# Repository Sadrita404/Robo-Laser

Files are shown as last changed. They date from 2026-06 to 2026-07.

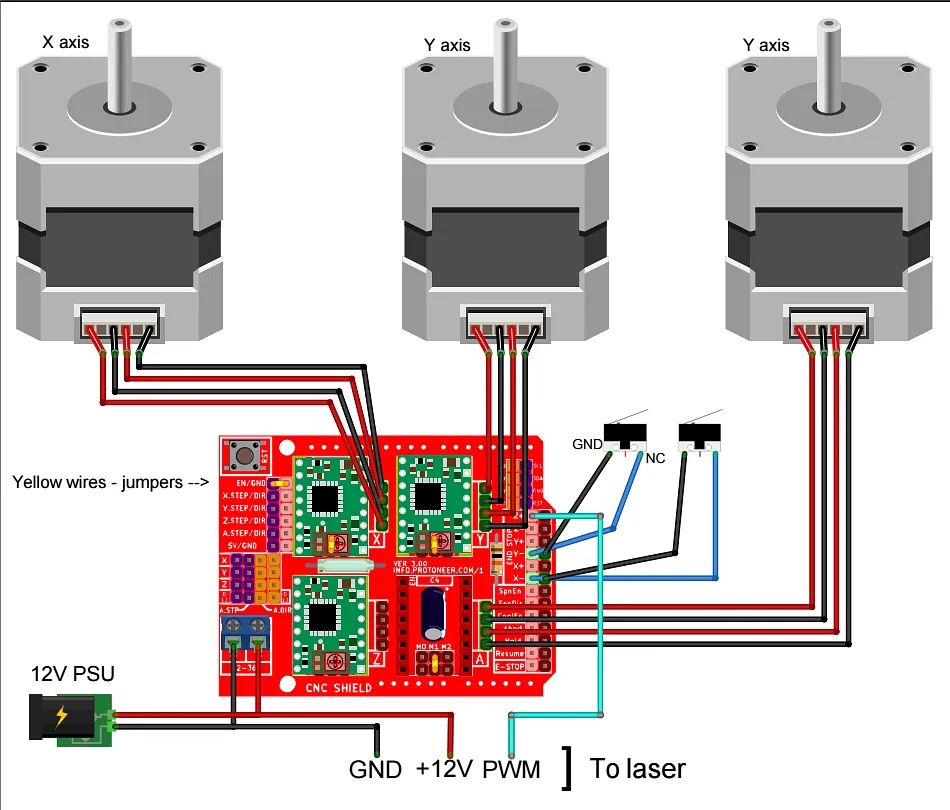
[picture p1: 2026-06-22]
IMAGE/Wiring Diagram Final .jpg

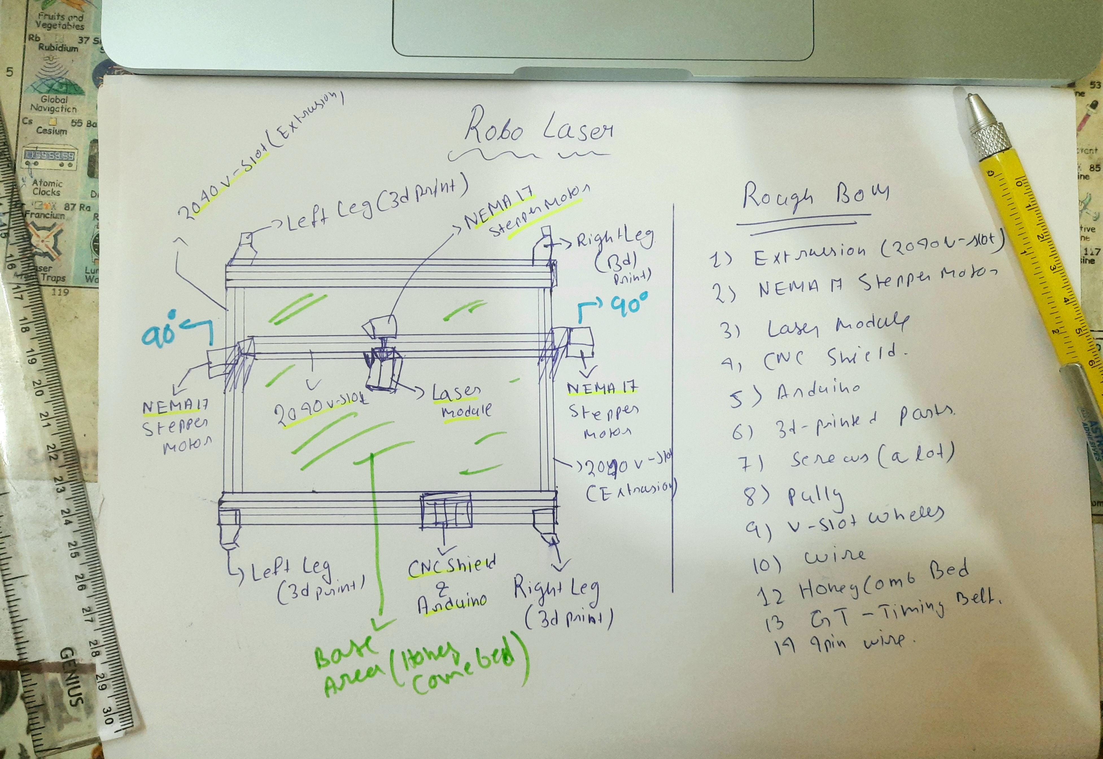
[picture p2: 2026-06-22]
IMAGE/sketch.jpg

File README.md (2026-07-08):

  <table border="0" cellpadding="0" cellspacing="0">
    <tr>
      <td align="center" style="background: #ffffff; border: 1px solid #d0d7de; border-radius: 12px; padding: 16px; box-shadow: 0 4px 12px rgba(0,0,0,0.05);">
        Rough Layout For The PCB
        <div style="margin-top: 12px; font-family: -apple-system, BlinkMacSystemFont, 'Segoe UI', Helvetica, Arial, sans-serif; font-size: 13px; color: #57606a; font-weight: 500;">
      </td>
    </tr>
  </table>
</div>

|Title | Robo Laser |
|:-- |:--|
|Author | Sadrita Neogi|

## Overview
It's an hobby grade laser engraver that I have made the model in fusion 360 and after that, I have specifically selected the components that fits the budget and it is easily modified and it can be later upgraded into something related to CNC. And this is an open source project.

### Why I chose this project?
I chose to build a CNC laser engraver because it combines both the hardware and the software and while making it I have learnt a lot about CAD design how to take dimension from data sheet and implemented in CAD also learned about how XY coordinate works in an CNC

### How to use this project
This can be used in various ways for me. I will use it to engrave in small MDF board for my projects, and I can also cut small things with it like if I want to make an keyboard, I can cut out the base plate for the keyboard with it with extreme accuracy and it will enhance the project quality. Also, it can be used in other way too.

---

<div align="center">
  <table border="0" cellpadding="0" cellspacing="0">
    <tr>
      <td align="center" style="background: #ffffff; border: 1px solid #d0d7de; border-radius: 12px; padding: 16px; box-shadow: 0 4px 12px rgba(0,0,0,0.05);">
        Rough Layout For The PCB
        <div style="margin-top: 12px; font-family: -apple-system, BlinkMacSystemFont, 'Segoe UI', Helvetica, Arial, sans-serif; font-size: 13px; color: #57606a; font-weight: 500;">
      </td>
    </tr>
  </table>
</div>

|  | CAD WORK |  |  
| :-: | :-: | :-: |
| Full Board Layout | Component Placement | Connection Map |
| Trace Routing Detail | Alternate Connection Map | Secondary Trace Detail |
| Component Placement 2 | Routing Detail 3 | Routing Detail 4 |
| Routing Detail 5 | Routing Detail 6 | Final Routing Detail |

---
## Wiring Diagram 

<p align="center">
  
  
</p>

## Setup -  [setup.md](https://github.com/Sadrita404/Robo-Laser/blob/main/setup.md)

Once the machine is assembled and wired, firmware needs to be installed so that it can move.

### Flashing GRBL onto the Arduino
GRBL is the firmware which is going to run on the Arduino and interpret the G-code commands. The installation is fairly simple.

1. **Download the Arduino IDE** from their site, a program which allows to flash the Arduino with firmware.
2. **Download GRBL source code** `.zip` file from the GitHub repository: https://github.com/gnea/grbl/releases and unzip the grbl file. 
   > **Note:** Before we proceed, we need to modify the `config.h` file inside grbl to account for the lack of the Z axis.
3. **Open Arduino IDE and import the grbl file** via: `Sketch` -> `Include Library` -> `Add .ZIP Library...` *(it says .ZIP but the uncompressed file should be chosen)*.
4. **Navigate to the grblUpload sketch** via: `File` -> `Examples` -> `grbl` -> `grblUpload`.
6. **Flash the sketch** through `Sketch` -> `Upload`.

---

### Connecting the Arduino to LaserGRBL

1. **Download LaserGRBL** from their website: https://lasergrbl.com and install it.
2. **Choose the correct port** and select **"115200" baud rate**, then click **Connect**. 

If the console shows `Grbl 1.1h`, the chip is connected.

##  Now for sending the G- Code to the Arduino I will use universal Gcode Sender 

**https://github.com/winder/Universal-G-Code-Sender**

- official website - https://winder.github.io/ugs_website/

- It is an open source software, which is used to control CNC machines to send G code to them and to use it

---
<div align="center">
  <h2> Final Look After Render </h2>
</div>

<p align="center">
  
</p>

<p align="center">
  
</p>

<p align="center">
  
</p>

<p align="center">
  
</p>

<div align="center">
  <h2> Bill of Materials</h2>
</div>

| Component Name | Purpose | Qty | Total Price | Source Link | Distributor |
| :--- | :--- | :---: | :---: | :---: | :---: |
| **4W Laser Engraver with adjustable Focus** | Laser cutting/engraving tool | 1 | $90 | [Amazon](https://www.amazon.in/LASER-TREE-20W-Adjustable-450nm/dp/B09BKJDPDJ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) | Amazon |
| **M5 Hex Nut** | General assembly fastening | 20 | $0.17 | [OnlyScrews](https://onlyscrews.in/products/m5-hex-nut-mild-steel-grey-dia-5mm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) | onlyscrews |
| **M5 x 10mm** | Extrusion/bracket fastening | 20 | $0.51 | [OnlyScrews](https://onlyscrews.in/products/m5-x-10mm-hex-allen-button-head-high-tensile10-9-black-oxide-screw-dia-5mm-length-10mm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) | onlyscrews |
| **M3 X 8mm Hex** | Motor/shield component mounting | 20 | $0.55 | [OnlyScrews](https://onlyscrews.in/products/m3-x-8mm-hex-allen-button-head-hight-tensile10-9-black-oxide-screw-dia-3mm-length-8mm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) | onlyscrews |
| **M5 X 35mm Hex** | Gantry/structural fastening | 20 | $0.76 | [OnlyScrews](https://onlyscrews.in/products/m5-x-35mm-hex-allen-button-head-high-tensile10-9-black-oxide-screw-dia-5mm-length-35mm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) | onlyscrews |
| **A4988 Driver Stepper Motor Driver** | Stepper motor control interface | 4 | $2.54 | [FlyRobo](https://www.flyrobo.in/a4988-driver-stepper-motor-driver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) | flyrobo |
| **Allen Key** | 	To fix the Rails | 1 | $2.11 | [onlyscrews](https://onlyscrews.in/products/allen-key-mm-set-m1-5-to-m10-chrome-vanadium-steel?variant=49975496671545) | amazon |
| **5 mm Tap set** | 		To make holes in the Extrusion Rod | 1 | $5.60 | [amazon](https://www.amazon.in/gp/product/B0D1R57NP7/ref=ox_sc_act_title_1?smid=A1ONML66JO9EQE&psc=1) | onlyscrews |
| **T-Slot inside corner connector for 2020** | Rigid frame joint support | 1 | $2.82 | [Robu](https://robu.in/product/easymech-2020-series-corner-slot-connector/?) | Robu |
| **Mech Endstop Switch** | Axis limit/homing switches | 8 | $3.99 | [Robu](https://robu.in/product/cnc-3d-printer-mech-endstop-switch/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) | robu |
| **T-Slot inside corner connector for 2020** | Rigid frame joint support | 1 | $2.82 | [Robu](https://robu.in/product/easymech-2020-series-corner-slot-connector/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) | robu |
| **NEMA 17 Stepper Motor, Bipolar, 1.5A** | Axis motion actuation | 3 | $22.79 | [Robu](https://robu.in/product/nema17-pr42hs40-1204af-02-4-2kg-cm-stepper-motor-d-type-shaft/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) | robu |
| **arduino uno r3 board** | Stepper motor control interface | 1 | $2.28 | [Robu](https://robu.in/product/arduino-uno-r3-ch340g-atmega328p-devlopment-board/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) | robu |
| **CNC Shield V3** | Stepper motor control interface | 1 | $1.48 | [FlyRobo](https://www.flyrobo.in/cnc-shield-v3-for-engraving-machine-3d-printer-a4988-drv8825-driver-expansion-board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) | flyrobo |
| **V Slot gantry wheel(625zz)** | Gantry linear movement | 14 | $8.46 | [FlyRobo](https://www.flyrobo.in/openbuilds-plastic-wheel-idler-pulley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) | flyrobo |
| **GT2 Timing Belt, 5M, 6mm width** | Linear motion drive | 1 | $4.66 | [Robu](https://robu.in/product/5-meter-x-gt2-open-timing-belt-6mm-width/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) | robu |
| **2040 Aluminum Extrusion, 1000mm V Slot** | Main structural frame | 2 | $19.6 | [Robu](https://robu.in/product/easymech-20x40-6t-slot-aluminium-extrusion-profile-1000-mm/) | robu |
| **2040 Aluminum Extrusion, 500mm V Slot** | Main structural frame | 3 | $17 | [Robu](https://robu.in/product/easymech-20x40-6t-slot-aluminium-extrusion-profile-500mm/) | robu |
| **20 Tooth 5mm Bore GT2 Timing Pulley** | Belt drive transmission | 6 | $2.09 | [FlyRobo](https://www.flyrobo.in/20-teeth-5mm-bore-gt2-black-timing-pulley-for-6mm-belt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) | flyrobo |
| **M5 X 100mm Hex** | Structural fastening | 1 | $0.34 | [link](https://3fparts.com/shop/m5-100mm-hex-bolt-din-933-stainless-steel-304-a2-70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) | Self - Sourced |
| **M4 X 100mm Hex** | Structural fastening | 2 | $0.89 | [OnlyScrews](https://onlyscrews.in/products/m4-x-100mm-hex-allen-socket-head-ss-304-screw-dia-4mm-length-100mm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) | onlyscrews |
| **M5 Profile Nuts** | Frame assembly hardware | 20 | $1.90 | [OnlyScrews](https://onlyscrews.in/products/m4-profile-nuts-mild-steel-with-nickel-plating-for-3030-series-t-nut-hammer-nut-1) | onlyscrews |
| **M4 Profile Nuts** | Frame assembly hardware | 20 | $1.84 | [OnlyScrews](https://onlyscrews.in/products/m4-profile-nuts-mild-steel-with-nickel-plating-for-2020-series-t-nut-hammer-nut) | onlyscrews |
| **M3 Profile Nuts** | Frame assembly hardware | 20 | $1.80 | [OnlyScrews](https://onlyscrews.in/products/m3-profile-nuts-mild-steel-with-nickel-plating-for-2020-series-t-nut-hammer-nut) | onlyscrews |
| **Cable with Connector for NEMA17 Motor** | Motor connection | 4 | $1.90 | [Robu](https://robu.in/product/pure-copper-1000-mm-cable-with-connector-for-nema17-stepper-motor/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) | robu |
| **Honeycomb Working Bed** | For the laser engraving area | 1 | $35 | [Robu](https://robu.in/product/two-trees-honeycomb-working-400x400-panel-set/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) | robu |
| **Power Supply** | to power up the circuit | 1 | $22 | [Robu](https://robu.in/product/mean-well-lrs-200-24-24v-8-8a-211-2w-smps/) | robu |

<div align="center">
  <table border="0" cellpadding="0" cellspacing="0" style="border-collapse: collapse; max-width: 600px;">
    <tr>
      <td style="background: #ffffff; border: 1px solid #d0d7de; border-radius: 12px; padding: 20px; box-shadow: 0 4px 12px rgba(0,0,0,0.05); font-family: -apple-system, BlinkMacSystemFont, 'Segoe UI', Helvetica, Arial, sans-serif;">
        <div style="font-size: 16px; font-weight: 600; color: #24292f; margin-bottom: 12px; border-bottom: 1px solid #d0d7de; padding-bottom: 8px;">
          Final Bill
        </div>
        <table width="100%" border="0" style="border-collapse: collapse; font-size: 14px; color: #57606a;">
          <tr>
            <td style="padding: 4px 0;">Component Subtotal:</td>
            <td align="right" style="font-weight: 500; color: #24292f;">$242</td>
          </tr>
          <tr>
            <td style="padding: 4px 0;"> Shipping:</td>
            <td align="right" style="font-weight: 500; color: #24292f;">$6.3</td>
          </tr>
          <tr>
            <td style="padding: 4px 0; padding-bottom: 8px;"> Tax:</td>
            <td align="right" style="font-weight: 500; color: #24292f;">$1.1</td>
          </tr>
          <tr style="border-top: 1px dashed #d0d7de;">
            <td style="padding: 12px 0 0 0; font-weight: 600; color: #24292f; font-size: 15px;">Net Total Cost:</td>
            <td align="right" style="padding: 12px 0 0 0; font-weight: bold; color: #2da44e; font-size: 18px;">$249.4</td>
          </tr>
          <tr>
            <td style="padding: 2px 0 0 0; font-size: 11px; color: #8c959f;">Projected Budget Allocation:</td>
            <td align="right" style="padding: 2px 0 0 0; font-weight: 500; font-size: 12px; color: #8c959f;">$250</td>
          </tr>
        </table>
      </td>
    </tr>
  </table>
</div>

I have provided the links to the parts that I will self - sourced , So that if a reader wanted to recreate this project they would be able to find all the parts..

**Project Under Hack Club**

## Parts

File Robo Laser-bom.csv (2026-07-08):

Name | Purpose | Quantity | Total Cost (USD) | Link | Distributor
Allen Key | To fix the Rails | 1 | 2.11 | https://onlyscrews.in/products/allen-key-mm-set-m1-5-to-m10-chrome-vanadium-steel?variant=49975496671545 | onlyscrews
5 mm Tap set | To make holes in the Extrusion Rod | 1 | 5.60 | https://www.amazon.in/gp/product/B0D1R57NP7/ref=ox_sc_act_title_1?smid=A1ONML66JO9EQE&psc=1 | amazon
4W Laser Engraver with adjustable Focus | Laser cutting/engraving tool | 1 | 90 | https://www.amazon.in/LASER-TREE-20W-Adjustable-450nm/dp/B09BKJDPDJ?mcid=b94e30e433d33609930a239af455c954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 | Amazon
M5 Hex Nut | General assembly fastening | 20 | 0.17 | https://onlyscrews.in/products/m5-hex-nut-mild-steel-grey-dia-5mm?currency=INR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 | onlyscrews
M5 x 10mm | Extrusion/bracket fastening | 20 | 0.51 | https://onlyscrews.in/products/m5-x-10mm-hex-allen-button-head-high-tensile10-9-black-oxide-screw-dia-5mm-length-10mm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 | onlyscrews
M3 X 8mm Hex | Motor/shield component mounting | 20 | 0.55 | https://onlyscrews.in/products/m3-x-8mm-hex-allen-button-head-hight-tensile10-9-black-oxide-screw-dia-3mm-length-8mm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 | onlyscrews
M5 X 35mm Hex | Gantry/structural fastening | 20 | 0.76 | https://onlyscrews.in/products/m5-x-35mm-hex-allen-button-head-high-tensile10-9-black-oxide-screw-dia-5mm-length-35mm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 | onlyscrews
A4988 Driver Stepper Motor Driver | Stepper motor control interface | 4 | 2.54 | https://www.flyrobo.in/a4988-driver-stepper-motor-driver?tracking=ads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 | flyrobo
Mech Endstop Switch | Axis limit/homing switches | 8 | 3.99 | https://robu.in/product/cnc-3d-printer-mech-endstop-switch/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 | robu
T-Slot inside corner connector for 2020 | Rigid frame joint support | 1 | 2.82 | https://robu.in/product/easymech-2020-series-corner-slot-connector/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 | robu
NEMA 17 Stepper Motor, Bipolar, 1.5A | Axis motion actuation | 3 | 22.79 | https://robu.in/product/nema17-pr42hs40-1204af-02-4-2kg-cm-stepper-motor-d-type-shaft/?gad_source=1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 | robu
arduino uno r3 board | Stepper motor control interface | 1 | 2.28 | https://robu.in/product/arduino-uno-r3-ch340g-atmega328p-devlopment-board/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 | robu
CNC Shield V3 | Stepper motor control interface | 1 | 1.48 | https://www.flyrobo.in/cnc-shield-v3-for-engraving-machine-3d-printer-a4988-drv8825-driver-expansion-board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 | flyrobo
V Slot gantry wheel(625zz) | Gantry linear movement | 14 | 8.46 | https://www.flyrobo.in/openbuilds-plastic-wheel-idler-pulley?tracking=ads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 | flyrobo
GT2 Timing Belt, 5M, 6mm width | Linear motion drive | 1 | 4.66 | https://robu.in/product/5-meter-x-gt2-open-timing-belt-6mm-width/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 | robu
2040 Aluminum Extrusion, 1000mm V Slot | Main structural frame | 2 | 19.6 | https://robu.in/product/easymech-20x40-6t-slot-aluminium-extrusion-profile-1000-mm/ | robu
2040 Aluminum Extrusion, 500mm V Slot | Main structural frame | 3 | 17 | https://robu.in/product/easymech-20x40-6t-slot-aluminium-extrusion-profile-500mm/ | robu
20 Tooth 5mm Bore GT2 Timing Pulley | Belt drive transmission | 6 | 2.09 | https://www.flyrobo.in/20-teeth-5mm-bore-gt2-black-timing-pulley-for-6mm-belt?tracking=ads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 | flyrobo
M5 X 100mm Hex | Structural fastening | 1 | 0.34 | https://3fparts.com/shop/m5-100mm-hex-bolt-din-933-stainless-steel-304-a2-70 | Self - Sourced
M4 X 100mm Hex | Structural fastening | 2 | 0.89 | https://onlyscrews.in/products/m4-x-100mm-hex-allen-socket-head-ss-304-screw-dia-4mm-length-100mm?currency=INR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 | onlyscrews
M5 Profile Nuts | Frame assembly hardware | 20 | 1.90 | https://onlyscrews.in/products/m4-profile-nuts-mild-steel-with-nickel-plating-for-3030-series-t-nut-hammer-nut-1 | onlyscrews
M4 Profile Nuts | Frame assembly hardware | 20 | 1.84 | https://onlyscrews.in/products/m4-profile-nuts-mild-steel-with-nickel-plating-for-2020-series-t-nut-hammer-nut | onlyscrews
M3 Profile Nuts | Frame assembly hardware | 20 | 1.80 | https://onlyscrews.in/products/m3-profile-nuts-mild-steel-with-nickel-plating-for-2020-series-t-nut-hammer-nut | onlyscrews
Cable with Connector for NEMA17 Stepper Motor | Motor connection | 4 | 1.90 | https://robu.in/product/pure-copper-1000-mm-cable-with-connector-for-nema17-stepper-motor/?gad_source=1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 | robu
Honeycomb Working Bed | For the laser engraving area | 1 | 35 | https://robu.in/product/two-trees-honeycomb-working-400x400-panel-set/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 | Robu
Power Supply | to power up the main circuit | 1 | 22 | https://robu.in/product/mean-well-lrs-200-24-24v-8-8a-211-2w-smps/ | Robu

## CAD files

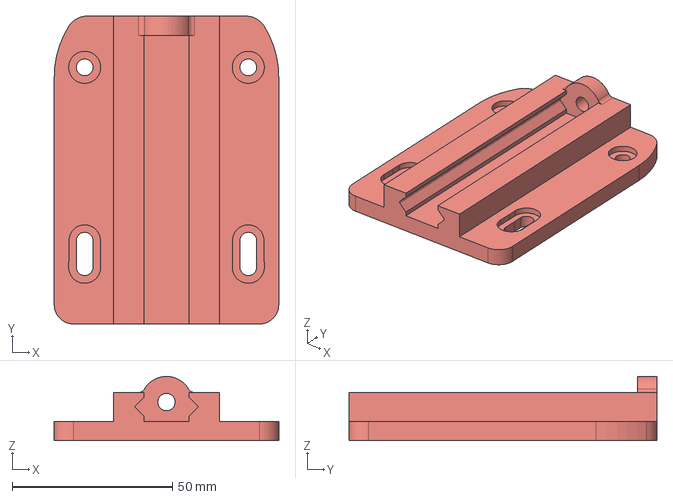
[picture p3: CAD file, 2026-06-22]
CAD/02 Laser Holder Base [x1].step
70.0 x 96.0 x 20.0 mm

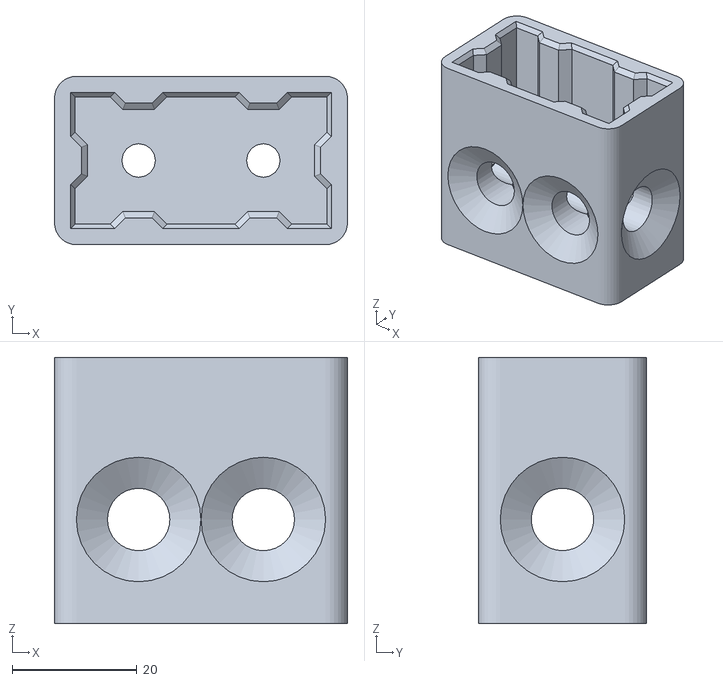
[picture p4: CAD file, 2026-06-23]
STL/[x2]M5 V-Slot 2040.stl
47.0 x 27.0 x 42.7

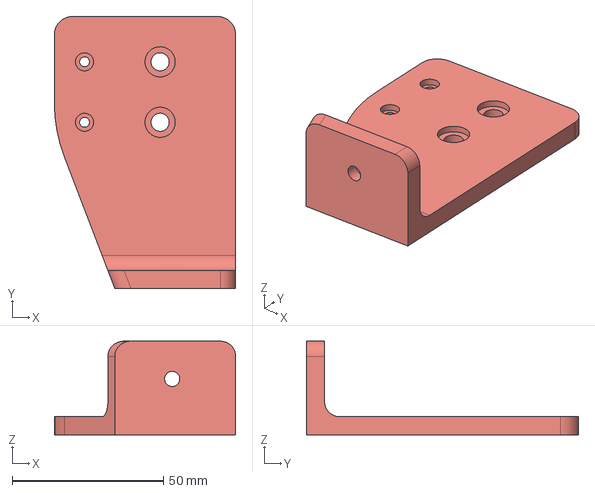
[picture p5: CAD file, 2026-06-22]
CAD/Right Leg.step
60.0 x 90.0 x 31.0 mm

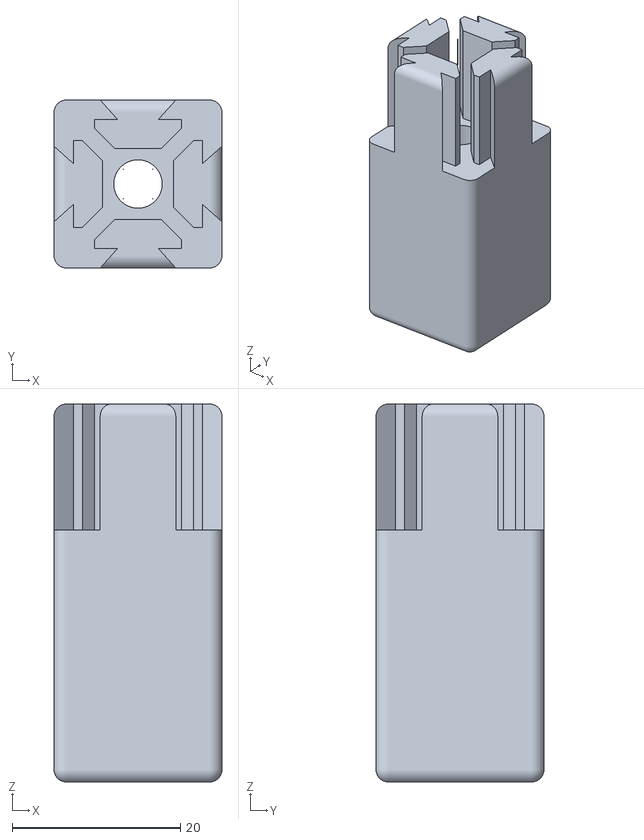
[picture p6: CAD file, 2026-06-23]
STL/[x2]V-Slot apping.stl
20.0 x 20.0 x 45.0

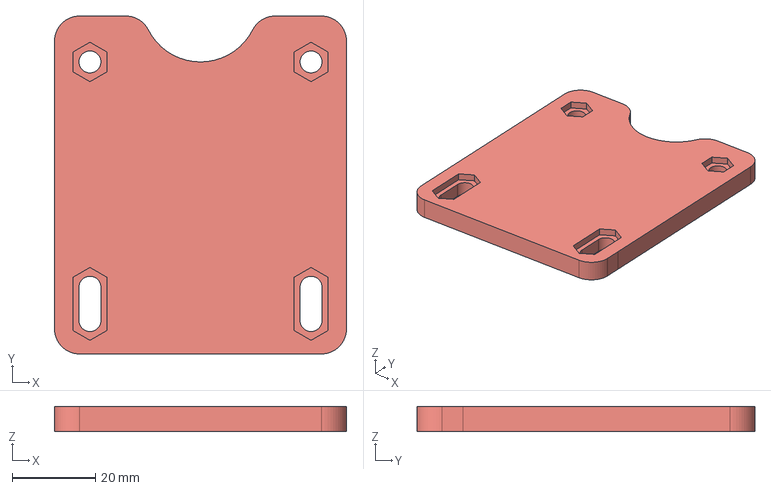
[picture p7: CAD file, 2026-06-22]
CAD/Y-Drive Side Panel.step
70.0 x 81.0 x 6.00 mm

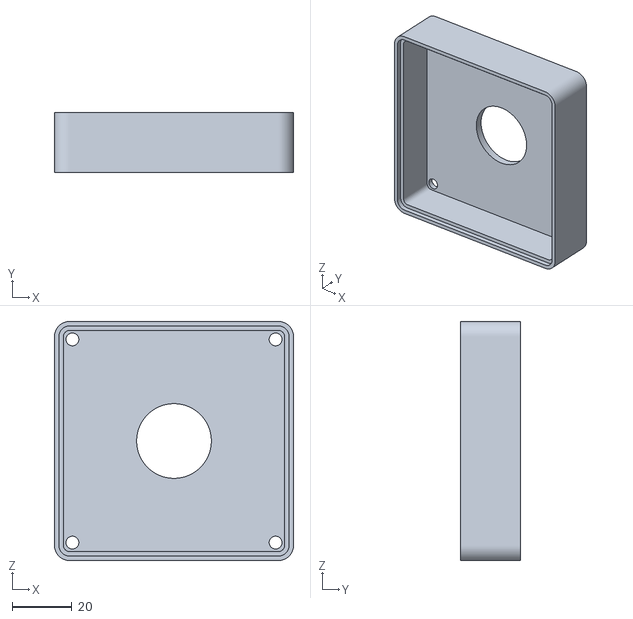
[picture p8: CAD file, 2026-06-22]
STL/[x1]E-Stop box top.stl
80.0 x 20.0 x 80.0

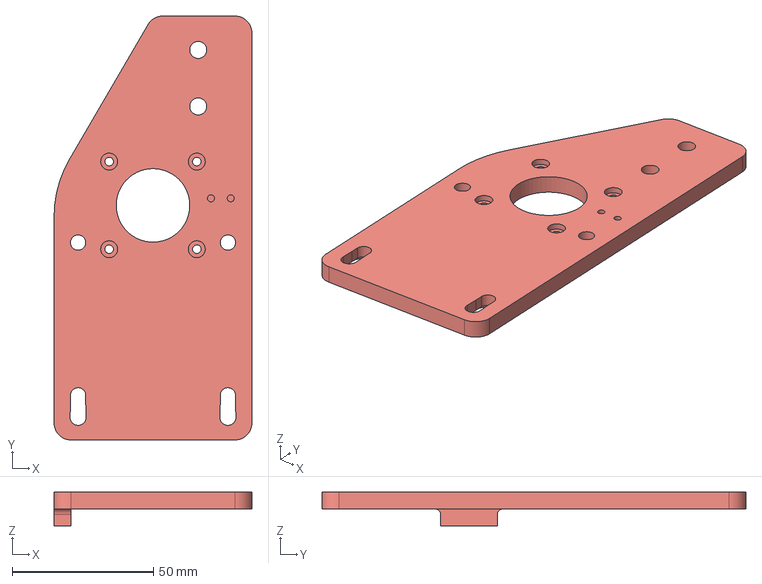
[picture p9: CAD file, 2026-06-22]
CAD/06 Y-Drive Panel L.step
70.0 x 150.0 x 12.0 mm

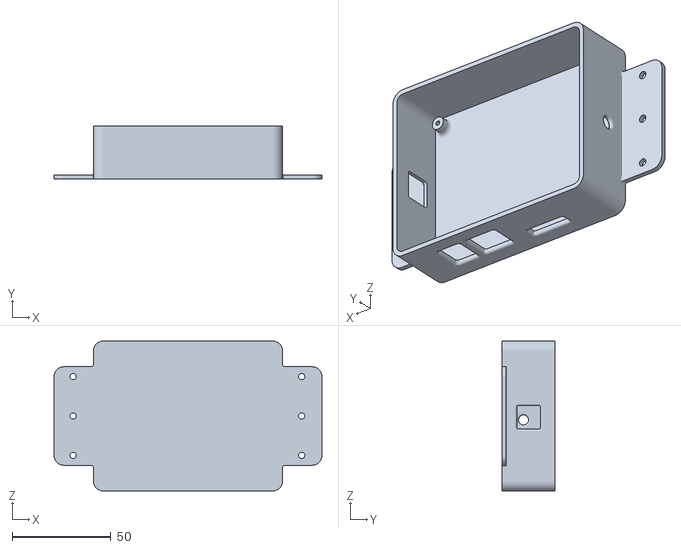
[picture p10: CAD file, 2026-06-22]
STL/[x1]Enclosure Body.stl
136.0 x 27.0 x 76.0

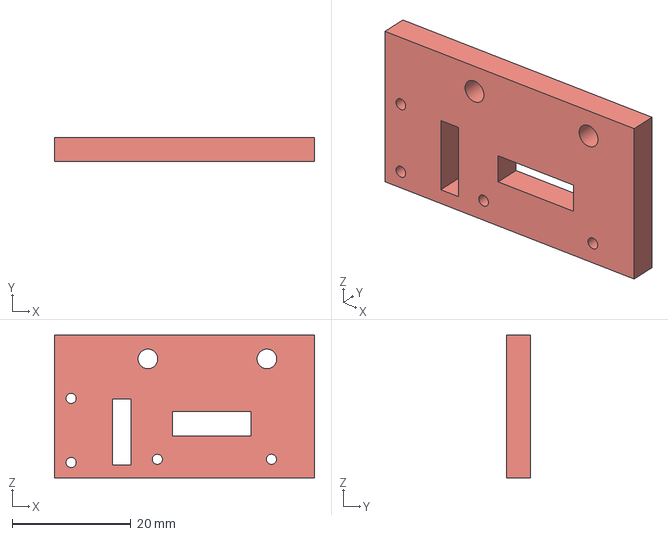
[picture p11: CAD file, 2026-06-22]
CAD/Limit switch mount.step
43.7 x 4.00 x 24.0 mm

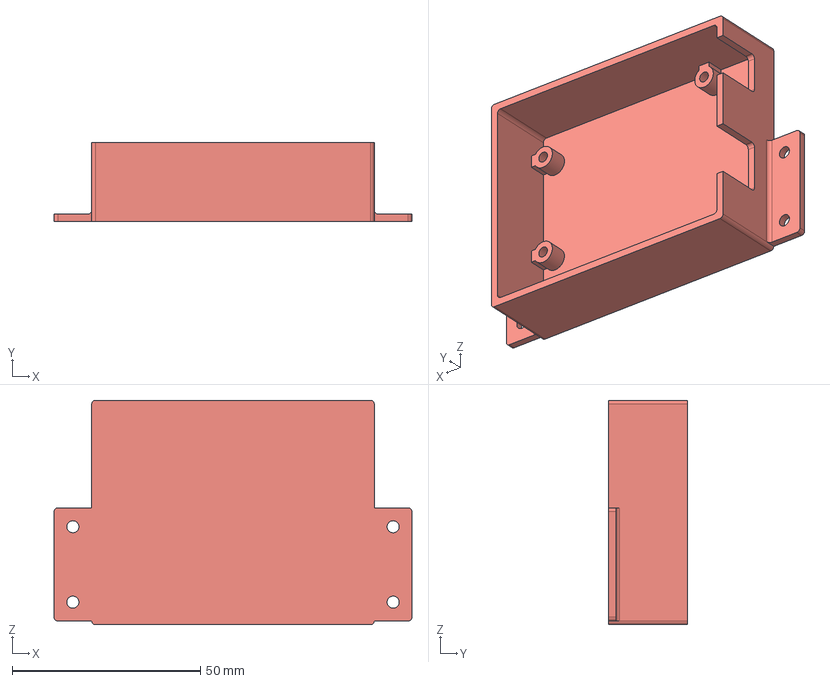
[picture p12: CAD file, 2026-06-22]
CAD/Uno and CNC Shield holder.step
95.0 x 21.0 x 59.6 mm

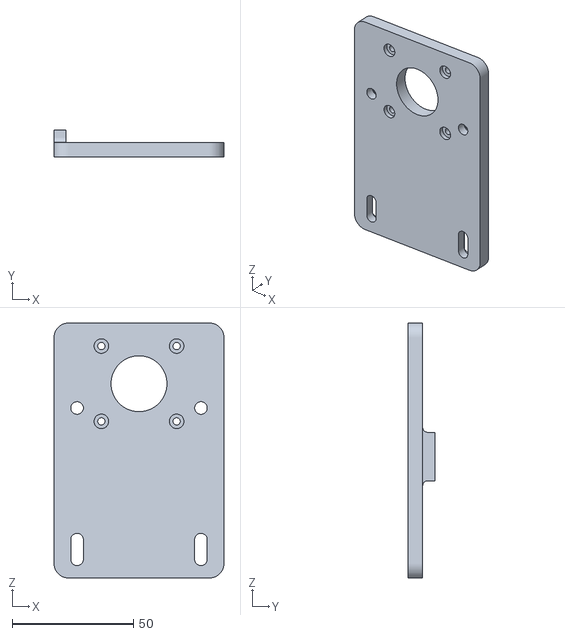
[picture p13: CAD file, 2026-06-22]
STL/[x4]X-Axis Stepper Mount.stl
70.0 x 11.0 x 105.0

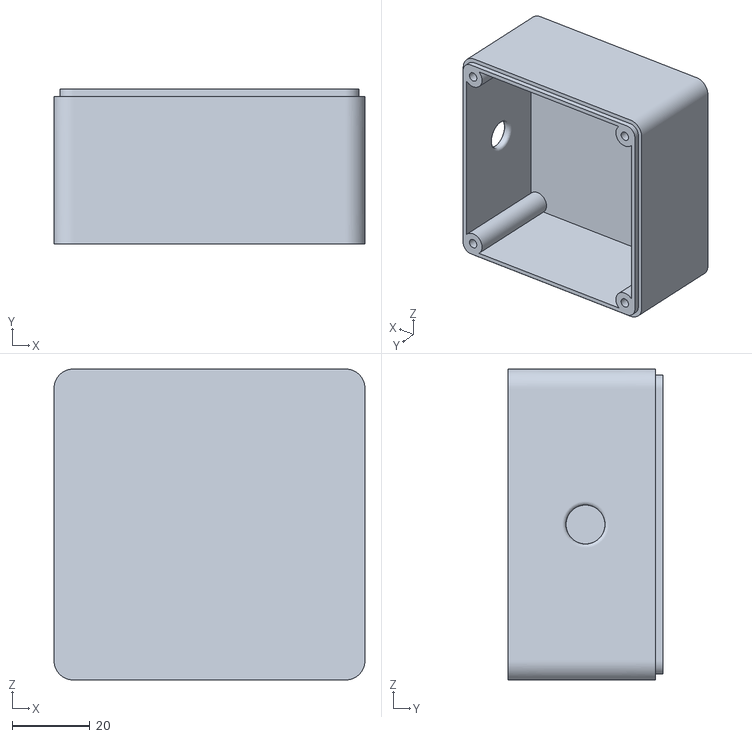
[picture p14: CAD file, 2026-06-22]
STL/[x1]E-Stop box bottom.stl
80.0 x 40.0 x 80.0

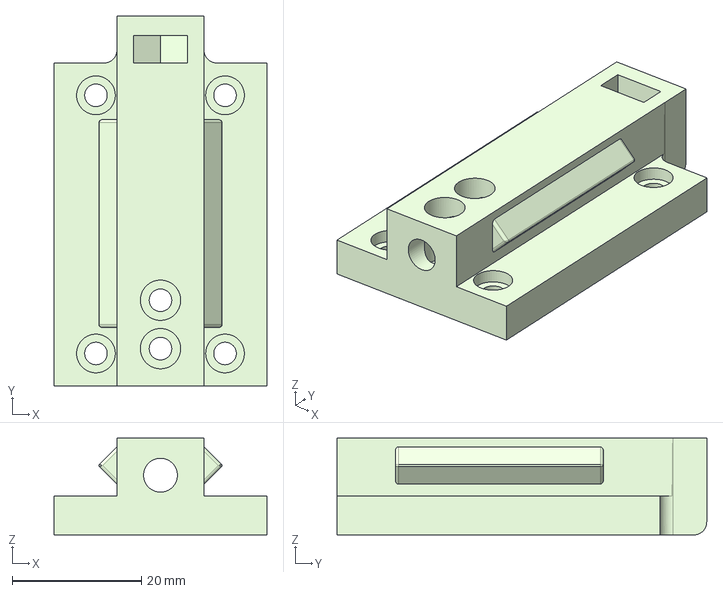
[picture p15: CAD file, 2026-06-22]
CAD/01 Laser Mount [x2].step
33.0 x 57.3 x 15.0 mm

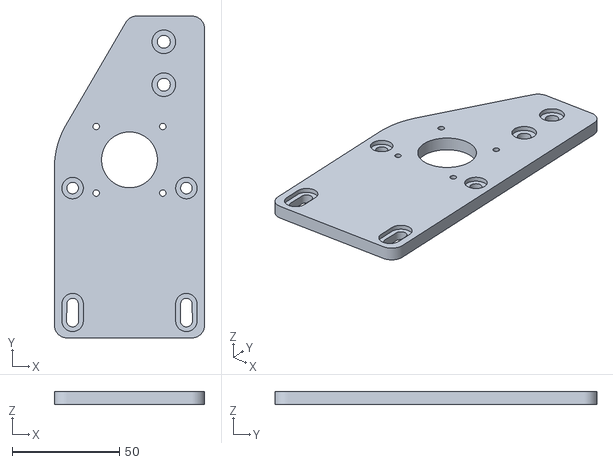
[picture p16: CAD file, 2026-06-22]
STL/[x2]Y-Drive Panel R.stl
70.0 x 150.0 x 6.00

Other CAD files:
STL/[x4]Y-Drive Side Panel.stl
CAD/03 X-Axis Stepper Mount.step
STL/[x1]Uno and CNC Shield holder.stl
CAD/Left Leg.step
CAD/01 Laser Mount [x2].f3d
CAD/02 Laser Holder Base [x1].f3d
CAD/03 X-Axis Stepper Mount.f3d
CAD/04 Laser Focus Knob.f3d
CAD/04 Laser Focus Knob.step
CAD/05 V-Wheel Bushing.f3d
CAD/05 V-Wheel Bushing.step
CAD/06 Y-Drive Panel L.f3d
CAD/Left Leg.f3d
CAD/Limit switch mount.f3d
CAD/Right Leg.f3d
CAD/Uno and CNC Shield holder.f3d
CAD/Y-Drive Side Panel.f3d
STL/[x1]Display Holder Back.stl
STL/[x1]Display Holder.stl
STL/[x1]Enclosrue Lid.stl
STL/[x1]Laser Focus Knob.stl
STL/[x1]Laser Mount 16mm x 40mm.stl
STL/[x1]Laser Mount 20mm x 40mm.stl
STL/[x2]Laser holder base.stl
STL/[x2]Left Leg.stl
STL/[x2]Right Leg.stl
STL/[x2]Y-Drive Panel L.stl
STL/[x40]V-Wheel Bushing v1.stl
STL/[x4]Limit switch mount.stl

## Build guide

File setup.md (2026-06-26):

## This are some of the thing that we need to keep in mind during building this 

For more details follow this - https://lasergrbl.com/usage/arduino-connection/

### I have use an unique way to setup software with extreme precision I went online searching for documentation for product that are available in online shops then I found this one which is listed on Amazon and they have good documentation and for building this kind of project, I think setting up the software with guided would be better
 PDF DOC - https://m.media-amazon.com/images/I/C1yvvKE-JJL.pdf

#### Flashing GRBL onto the Arduino

1. Download the Arduino IDE from their site, a program which allows to flash the Arduino with firmware.
2. Download GRBL source code.zip file from the GitHub repository: https://github.com/gnea/grbl/releases and unzip the grbl file. Before we proceed a we need to modify the config.h file inside grbl to account for the lack of the Z axis.
3. 
Screenshot 2026-06-23 at 2.59.49 AM

## Now , 
Screenshot 2026-06-23 at 3.00.07 AM

1. Open Arduino IDE and import the grbl file via: Sketch->Include Library->add .zip library.
2. Navigate to the grblUpload sketch via: File -> Examples -> grbl -> grblUpload
3. Connect the Arduino to the laptop via USB (make sure the correct board and port is selected).
4. Flash the sketch through Sketch->Upload

After that we need to connect  the Arduino to LaserGRBL(through which I will control the laser) is simple. First, download LaserGRBL from their website: [https://lasergrbl.com](https://lasergrbl.com) and install it. Then again connect the Arduino to the laptop  via USB, choose the correct port and select "115200" baud rate, then click connect. If the console shows "Grbl 1.1h, the chip is connected.

### Now to configure it correctly go through the doc below : - 
[DOC PDF ](https://lasergrbl.com/wp-content/uploads/2020/05/Grbl-Configuration-ENG.pdf)

 #### Key changes Main

### 1) Configuring Stepper Drivers

**Microstepping Jumpers**

Under each stepper driver socket on the CNC Shield V3 are three jumper pairs (MS1, MS2, MS3). These set the microstepping mode:

| MS1 | MS2 | MS3 | Microstepping (A4988) |
| :---: | :---: | :---: | :---: |
| **OFF** | **OFF** | **OFF** | Full step |
| **ON** | **OFF** | **OFF** | 1/2 step |
| **OFF** | **ON** | **OFF** | 1/4 step |
| **ON** | **ON** | **OFF** | 1/8 step |
| **ON** | **ON** | **ON** | 1/16 step |

Most 3018 CNC routers use 1/8 or 1/16 microstepping. Higher microstepping = smoother motion but lower maximum speed (due to GRBL’s step frequency limit). 1/8 stepping is a good balance.

### Setting Current Limit (VREF)
The most critical stepper driver adjustment is current limit. Over-current burns motors and drivers; under-current causes missed steps. Use a multimeter in DC voltage mode:

Measure VREF between the driver’s trimpot (center of the small adjustable potentiometer) and GND.

1)**For A4988: Imax = VREF / 0.625 (with 0.1Ω sense resistors). Set VREF = (rated motor current × 0.625).**

2)**For DRV8825: Imax = VREF / 0.5. Set VREF = (rated motor current / 2).**

3)**Start at 70–80% of motor rated current. For a 1.7A NEMA17: VREF ≈ 0.85V on A4988.**

### 2) GRBL Settings ($ Parameters)

**Type $$ in your GRBL sender to see all current settings. Here are the most important ones:**

| Parameter | Description | Typical Value (3018) |
| :---: | :--- | :--- |
| **$0** | Step pulse time (µs) | 10 |
| **$1** | Step idle delay (ms) | 25 (255 = always on) |
| **$2** | Step port invert (bitmask) | 0 |
| **$3** | Direction port invert (bitmask) | 0 (adjust if axes move wrong direction) |
| **$4** | Step enable invert | 0 |
| **$5** | Limit pin invert (NC vs NO switches) | 0 (NC=1) |
| **$10** | Status report mask | 1 |
| **$20** | Soft limits enable | 0 (1 if homing enabled) |
| **$21** | Hard limits enable | 0 (1 with limit switches) |
| **$22** | Homing cycle enable | 0 (1 with limit switches) |
| **$100** | X steps/mm | 800 (varies by machine) |
| **$101** | Y steps/mm | 800 |
| **$102** | Z steps/mm | 800 |
| **$110** | X max rate (mm/min) | 800 |
| **$111** | Y max rate (mm/min) | 800 |
| **$112** | Z max rate (mm/min) | 400 (Z is slower) |
| **$120** | X acceleration (mm/s²) | 40 |
| **$130** | X max travel (mm) | 300 (your machine’s X range) |

Change any setting by typing the parameter and value, e.g.: $100=800 followed by Enter. Changes are saved to Arduino EEPROM immediately.

### 3) Calibrating Steps Per mm

**Getting steps/mm right is fundamental — incorrect values mean your G-code dimensions do not match reality. Here is the calculation and calibration process:**

```
Steps/mm = (Motor steps per revolution × Microstepping) / (Lead screw pitch mm)

Example: NEMA17 (200 steps/rev) × 1/8 microstepping / 2mm lead pitch
= 200 × 8 / 2 = 800 steps/mm

For belt drive: replace pitch with (belt pitch × pulley teeth)
Example: GT2 belt, 20-tooth pulley → pitch distance = 2mm × 20 = 40mm/rev
Steps/mm = (200 × 16) / 40 = 80 steps/mm
```

### 4)  Homing Switches and Limit Switches

Homing switches allow GRBL to find a consistent machine origin (machine zero) at power-on. Limit switches prevent the machine from crashing into its mechanical ends. These can be the same switches — GRBL supports both modes.

**Switch Types**
- 1) Normally Closed (NC): Switch is closed (circuit active) when not triggered. Opens when the axis reaches the switch. Safer — a broken wire triggers a fault rather than being invisible.

- 2) Normally Open (NO): Switch is open until triggered. Simpler wiring but a broken wire is invisible to GRBL.

**Wiring Limit Switches**
Each axis minimum switch connects to the Xmin, Ymin, Zmin headers on the CNC shield. Connect one switch terminal to the signal pin and the other to GND. No pull-up resistors are needed — the CNC shield or Arduino provides internal pull-ups on limit inputs.

#### Enabling Homing

```
$22=1   ; Enable homing cycle
$23=0   ; Homing direction mask (0 = home to -X, -Y, +Z)
$24=25  ; Homing feed rate (mm/min) - slow speed for switch contact
$25=500 ; Homing seek rate (mm/min) - fast approach speed
$26=250 ; Homing debounce delay (ms)
$27=1   ; Homing pull-off distance (mm) - backs off switch after homing
$21=1   ; Enable hard limits (optional - halts machine if limit hit)
$20=1   ; Enable soft limits (requires homing to be done first)

```

After enabling homing, type $H to run the homing cycle. The machine will seek each axis minimum (or maximum for Z) at the seek rate, back off, and re-approach slowly for accurate repeatability.

### This are some of the comands that I learn during, searching about the software 

**Key G-code Commands to Know**

```
G28       ; Return to home (machine zero)
G0 X0 Y0  ; Rapid move to work zero (X=0, Y=0)
G1 Z-1 F100  ; Feed move: cut 1mm into material at 100mm/min
G91       ; Set incremental positioning mode
G90       ; Set absolute positioning mode (default)
M3 S1000  ; Spindle on clockwise at 1000 RPM (if spindle is PWM-controlled)
M5        ; Spindle off
```

##  Now for sending the G- Code to the Arduino I will use universal Gcode Sender 

**https://github.com/winder/Universal-G-Code-Sender**

- official website - https://winder.github.io/ugs_website/

- It is an open source software, which is used to control CNC machines to send G code to them and to use it

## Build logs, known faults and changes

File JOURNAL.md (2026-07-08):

| Title | Robo Laser|
| :-- | :---|
|Author |Sadrita Neogi|
|Type | Laser Engraver  |
Total Hrs | 21.5 |

# Image Render

_Time spent: 0.3333333333333333h_

Finally, I have done with all the CAD work firmware and BOM now it's time to render some good images so that I can put it in my Git 

---
### Front 

Screenshot 2026-06-23 at 12.00.13 AM

### Back 

Screenshot 2026-06-23 at 12.00.26 AM

### Side 

Screenshot 2026-06-23 at 12.00.39 AM

### Top 

Screenshot 2026-06-23 at 12.00.52 AM

Image Render in Fusion 360 
-

Screenshot 2026-06-23 at 3.06.41 AM

# Firmware For Laser Engraver

_Time spent: 0.6666666666666666h_

#### Flashing GRBL onto the Arduino

1. Download the Arduino IDE from their site, a program which allows to flash the Arduino with firmware.
2. Download GRBL source code.zip file from the GitHub repository: https://github.com/gnea/grbl/releases and unzip the grbl file. Before we proceed a we need to modify the config.h file inside grbl to account for the lack of the Z axis.
3. 
Screenshot 2026-06-23 at 2.59.49 AM

## Now , 
Screenshot 2026-06-23 at 3.00.07 AM

1. Open Arduino IDE and import the grbl file via: Sketch->Include Library->add .zip library.
2. Navigate to the grblUpload sketch via: File -> Examples -> grbl -> grblUpload
3. Connect the Arduino to the laptop via USB (make sure the correct board and port is selected).
4. Flash the sketch through Sketch->Upload

After that we need to connect  the Arduino to LaserGRBL(through which I will control the laser) is simple. First, download LaserGRBL from their website: [https://lasergrbl.com](https://lasergrbl.com) and install it. Then again connect the Arduino to the laptop  via USB, choose the correct port and select "115200" baud rate, then click connect. If the console shows "Grbl 1.1h, the chip is connected.

### Now to configure it correctly go through the doc below : - 
[DOC PDF ](https://lasergrbl.com/wp-content/uploads/2020/05/Grbl-Configuration-ENG.pdf)

# Now wiring

_Time spent: 1.166666666666667h_

We need to enable the board by placing a jumper on those two pins ( to short this point to start it..)

Screenshot 2026-06-23 at 2.49.28 AM

Screenshot 2026-06-23 at 2.49.10 AM

Screenshot 2026-06-23 at 2.50.15 AM

Screenshot 2026-06-23 at 2.41.43 AM

Screenshot 2026-06-23 at 2.44.38 AM

Pad Selection 
Screenshot 2026-06-23 at 2.51.21 AM

---
### Final Wiring Diagram 

Wiring Diagram Final

#  CAD Assembly Done..

_Time spent: 2h_

Finally after lot of Assembly the final model is ready now I need to export all the stl file and the step file for this project that are neede to 3d Print and I also need to make the BOM for this I have made one rough BOM but need a bit of polish

---
### Front View
Screenshot 2026-06-22 at 11.56.33 PM

### Side View 
Screenshot 2026-06-22 at 11.56.42 PM

### Back View
Screenshot 2026-06-22 at 11.56.51 PM

### Top View
Screenshot 2026-06-22 at 11.56.57 PM

# Adding the End Stop Switch

_Time spent: 0.6666666666666666h_

Adding the End Stop Switch  to the model and after searching for a lot of place about the CAD model of the End Stop , but I couldn't find so I had to make it by my own and I have made it pretty well for me. I like it and it just done the work.

Screenshot 2026-06-22 at 11.53.21 PM

end stop added to the frame of both sides
Screenshot 2026-06-22 at 11.53.30 PM

#  Laser Module Added

_Time spent: 0.3333333333333333h_

After completing with the overall was now I have added the leisure module to the front cover plate along with the knob that it is used to adjust the height of the module

Screenshot 2026-06-22 at 11.52.30 PM

# Added the height adjusting knob

_Time spent: 2h_

Added the height adjusting knob this note can be adjusted based on which material we are going to use the engraver, so according to the Power of the laser, we will adjust the height of the module

Screenshot 2026-06-22 at 11.51.28 PM

Screenshot 2026-06-22 at 11.51.45 PM

Screenshot 2026-06-22 at 11.51.59 PM

#  Laser Module Holding Plate

_Time spent: 2.666666666666667h_

Finally, after choosing and laser engraver with the budget that I have, so I got the data sheet about and getting after the dimension I designed the cover plate to hold the laser engraver module and I have measured the dimension and according to that, I have designed the holder plate and I have designed the front part and the second part, and after that, I have also install the bearing V slot wheels in the rails.

Screenshot 2026-06-22 at 11.48.45 PM

Screenshot 2026-06-22 at 11.49.30 PM

Screenshot 2026-06-22 at 11.50.21 PM

here I have added the V - Slot wheels for for the smooth movement of the plate
Screenshot 2026-06-22 at 11.50.49 PM

#  Added the Control Unit to the frame and Case

_Time spent: 1.166666666666667h_

Added the Control Unit  in an box that I design and I took the model of the Arduino Uno and the CNC shield form Grab CAD and I have addde both the in the case and the dimenssion of the case is also according to the size of the Arduino.

Screenshot 2026-06-22 at 10.56.25 PM

Screenshot 2026-06-22 at 10.57.12 PM

Screenshot 2026-06-22 at 10.58.04 PM

Screenshot 2026-06-22 at 10.58.16 PM

#  Added the Top Arm

_Time spent: 0.6666666666666666h_

So after completing designing the base frame I went to make the top arm where the lase will be mounted and it wil be act as the x - axis of the Robo Laser 

---
added the arm 
Screenshot 2026-06-22 at 9.57.59 PM

Screenshot 2026-06-22 at 9.58.11 PM

final look 
Screenshot 2026-06-22 at 9.58.26 PM

#  Design the stepper motor holding plate

_Time spent: 4.333333333333333h_

Now I went to design  the stepper motor holding plate and I have also get an good CAD model of the NEEMA 17 motor in Grab CAD so I use that and then I took the dimensions from the data sheet and started designing the motor plate also I have design the sprocket wheel holder on that axis such that it will move in good directiion 

---
stepper motor holding plate 

Screenshot 2026-06-22 at 9.44.39 PM

Screenshot 2026-06-22 at 9.45.00 PM

---
Now adding the stepper motor holding plate in the Main Frame 

Screenshot 2026-06-22 at 9.34.48 PM

Screenshot 2026-06-22 at 9.34.18 PM

---
Added the stepper motor in the plate 

Screenshot 2026-06-22 at 9.35.47 PM

Screenshot 2026-06-22 at 9.37.19 PM

---
Design the holding plate for the sprokete 

Screenshot 2026-06-22 at 9.51.39 PM

Screenshot 2026-06-22 at 9.51.48 PM

Screenshot 2026-06-22 at 9.37.58 PM

added the v - slot wheel 
Screenshot 2026-06-22 at 9.38.36 PM

Screenshot 2026-06-22 at 9.39.11 PM

Screenshot 2026-06-22 at 9.39.41 PM

Screenshot 2026-06-22 at 9.40.14 PM

added in the both side of the frame .

Screenshot 2026-06-22 at 9.41.11 PM

Screenshot 2026-06-22 at 9.41.33 PM

at this point the frame looks to be how I draw it and it is turing into the real one ...

#  Started Designing the frame

_Time spent: 4h_

My first approach was to create the frame out of straight aluminium tubes and linear bearings, using 3d printed joints and supports. Then realised that if I were to make a bigger engraver requiring longer tubes, they could start bending under the weight and the laser could loose its focus or accuracy.

So today I went into fusion 360 and made the frame and leg join .

---
Base Frame 



Screenshot 2026-06-22 at 9.17.52 PM

---
Added the L - Joint to all 4 corner for more stability 
Screenshot 2026-06-22 at 9.18.27 PM

---
Designing the Leg Joint this took me lot of time

Screenshot 2026-06-22 at 9.27.08 PM

Screenshot 2026-06-22 at 9.27.22 PM

---
Added the Leg Joint 

Screenshot 2026-06-22 at 9.20.23 PM

----
Added it in all four leg 
Screenshot 2026-06-22 at 9.22.52 PM

#  Done Sketching the Robo Laser

_Time spent: 1.5h_

So today I started Sketching the Robo Laser like the basic structure of it such that later when I am designing it in the CAD it will work as an reference also I made an rought bom for this project. And I have made the drawing overall good and form it we can identify the type of movement the Robo laser will have .



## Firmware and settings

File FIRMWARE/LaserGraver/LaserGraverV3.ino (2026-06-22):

#include "Serial.h"
#include "Global.h"

void setup() {
  Serial.begin(115200);
  Serial.println(F("---=== FP myCNC v3 ===---"));
  Serial.println(F("by Dr. Failov."));
  Serial.print(F("Build date: "));
  Serial.println(__DATE__);
  Serial.print(F("Free RAM: "));
  Serial.print(freeRam());
  Serial.println(F(" bytes"));
  
  pinMode(LED_PIN, OUTPUT);
  pinMode(LASER_PIN, OUTPUT);
  pinMode(X_EN_PIN, OUTPUT); 
  
  digitalWrite(LED_PIN, HIGH);
  digitalWrite(LASER_PIN, LOW);
  digitalWrite(X_EN_PIN, HIGH);

  Serial.println(F("![Ready]!"));
}

void loop() {
  checkSerial();
}

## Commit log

2026-06-22 CAD all .step & .f3d file added
2026-06-22 Firmware added (grbl)
2026-06-22 all STL file for print added
2026-06-23 bom added
    [Robo Laser-bom.csv]
2026-06-27 Update Robo Laser-bom.csv
    [Robo Laser-bom.csv]
